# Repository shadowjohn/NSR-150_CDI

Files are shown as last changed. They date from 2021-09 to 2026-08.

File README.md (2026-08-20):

# NSR-150_CDI
利用 Nodemcu V2 開發的 NSR-150 可程式化 CDI
<br>
<br>
<h2>動機：</h2>
騎了NSR五年多，這陣子翻維修手冊，看到 CDI 的接線圖<br>
一直以來都覺得這是一塊很巨大的拚圖，想著想著就推著自己往前走，心中閃過一個想法<br>
不如~來自製一顆可程式的 CDI 吧~~~<br>
<br>
<br>
<h2>
Author：羽山 (https://3wa.tw)<br>
Author：@FB 田峻墉
</h2>
<h2>版本：</h2>
V0.5
<br>
<h2>最初發布時間：</h2>
2021-09-09
<br>
<h2>最後更新時間：</h2>
2026-08-21
<br>
<h2>Nodemcu 使用接腳(V0.1~V0.3版)：</h2>
<ul>
  <li>D1：脈衝 PWM 輸入</li>
  <li>D6：點火 輸出</li>
</ul>
<br>
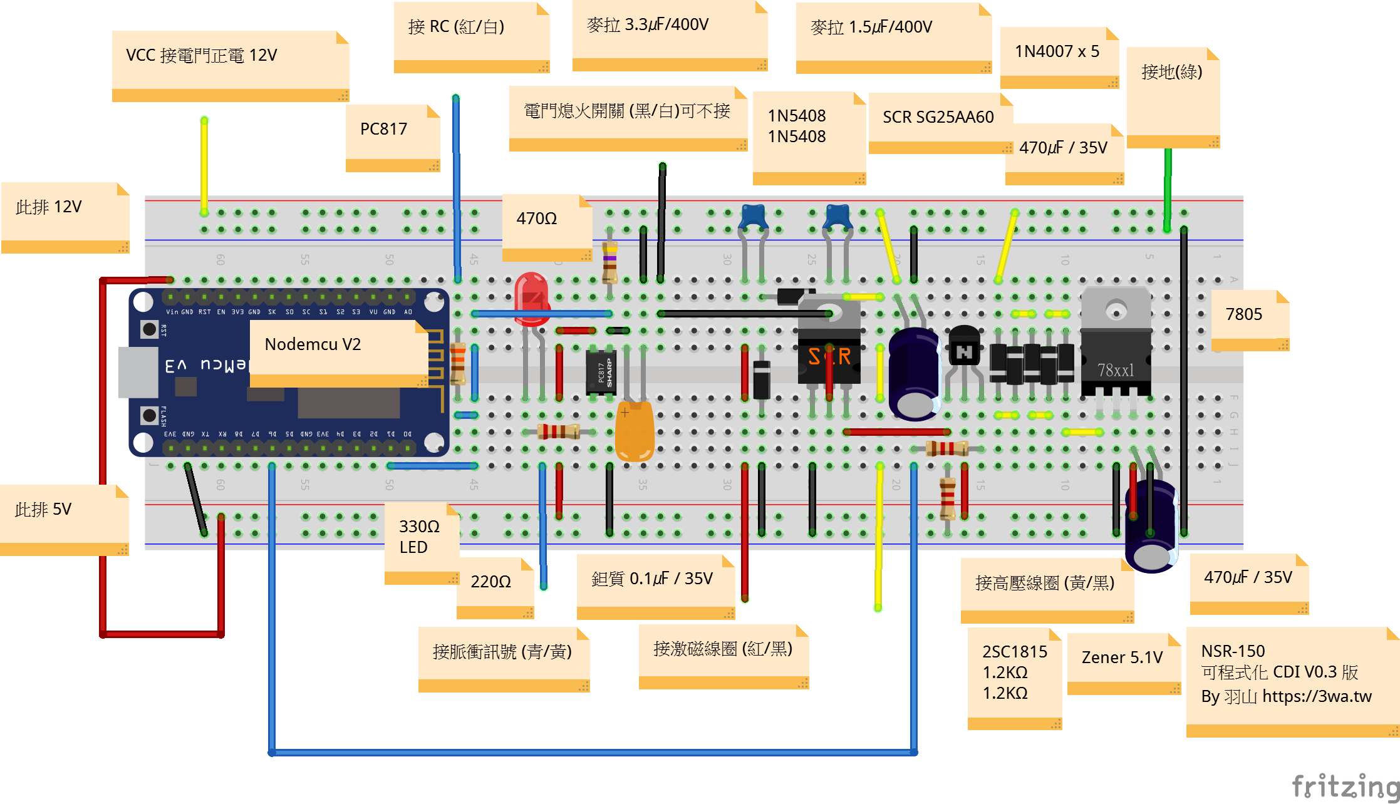
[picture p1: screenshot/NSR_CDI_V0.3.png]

<p align="center">(V0.3 版接線圖)</p>
<br>
<br>
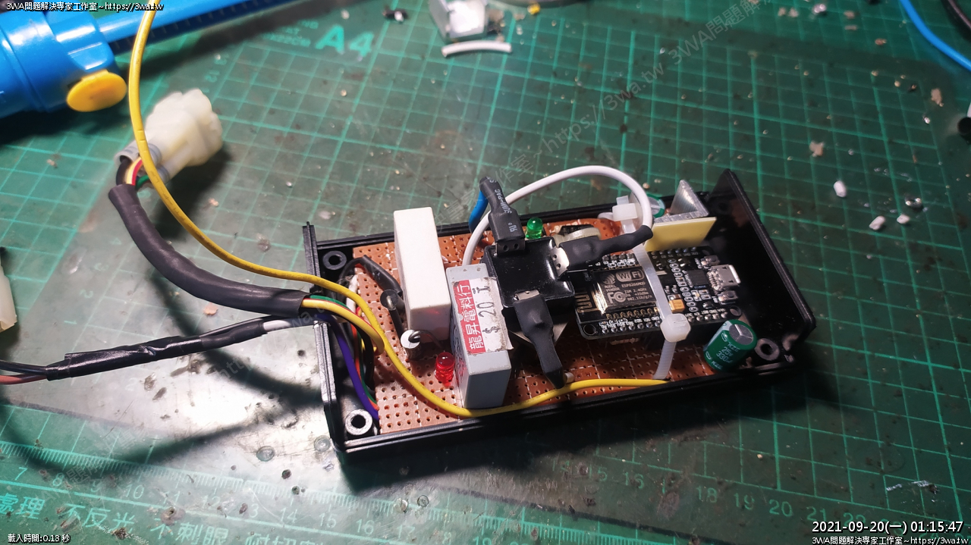
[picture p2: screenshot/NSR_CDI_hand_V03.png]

<p align="center">(V0.3 版成品圖)</p>
<br>
<br>
<h2>Nodemcu 使用接腳(V0.4~V0.5版)：</h2>
<ul>
  <li>D1：脈衝 PWM 輸入</li>
  <li>D4：RC 訊號輸出</li>  
  <li>D6：點火 輸出</li>  
</ul>
<br>
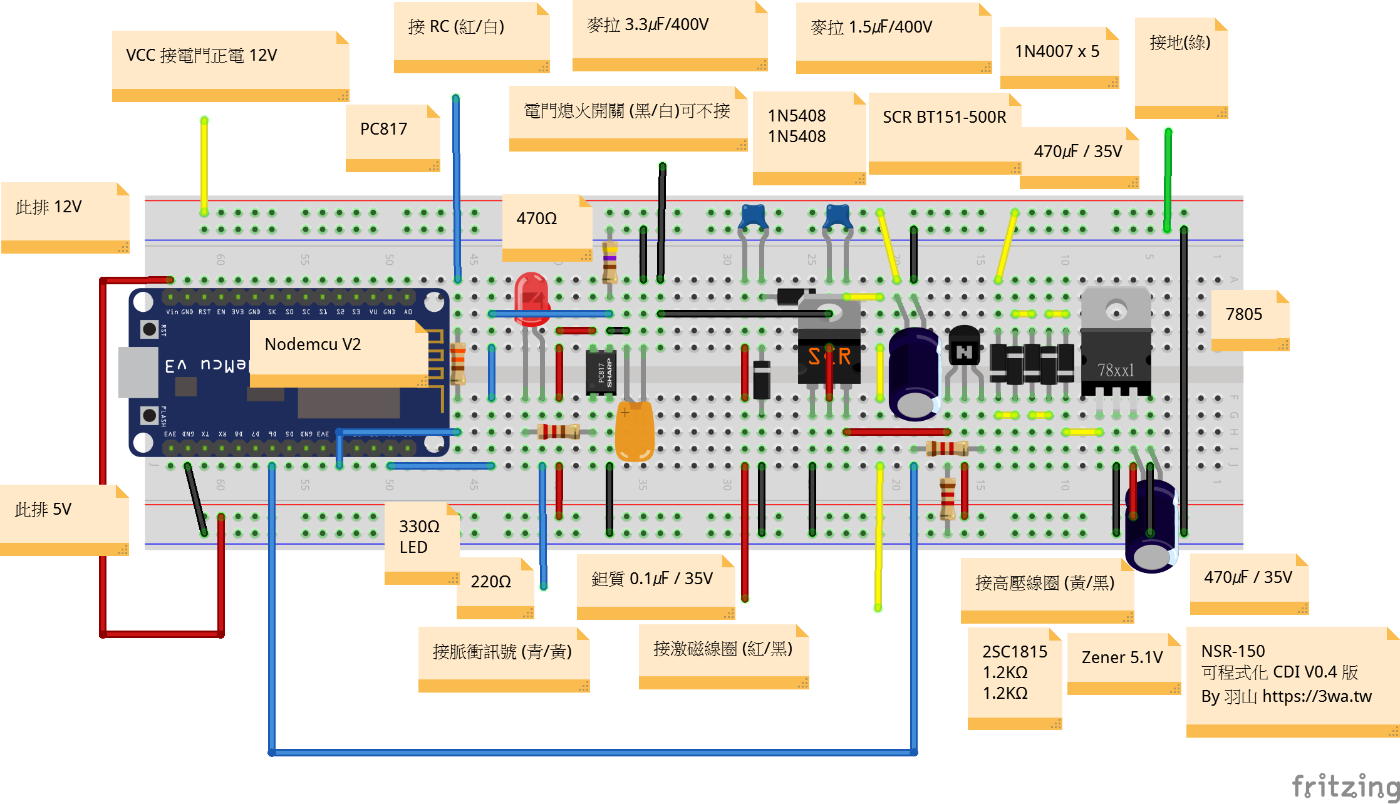
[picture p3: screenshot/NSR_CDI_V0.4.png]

<p align="center">(V0.4 版接線圖)</p>
<br>
<br>
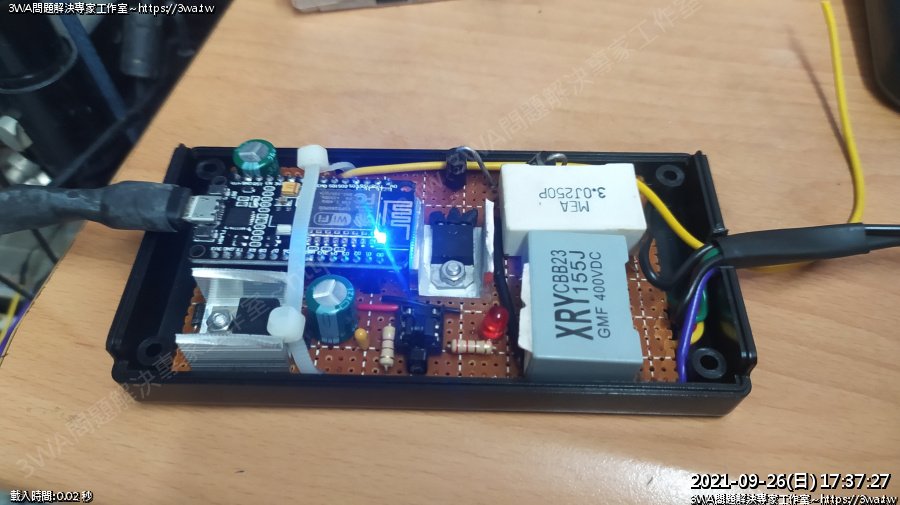
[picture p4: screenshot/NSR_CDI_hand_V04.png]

<p align="center">(V0.4 版成品圖)</p>
<br>
<br>
<br>
<h2>各版本說明：</h2>
<table>
  <thead>
  <tr>
    <th>版本</th>
    <th>補充說明</td>
    <th>適用程式</td>
  </tr>
  </thead>
  <tbody>
  <tr>
    <td>0.1~0.3</td>
    <td>基本版</td>
    <td>      
      (各版本的程式皆可運作)<br>
      https://github.com/shadowjohn/NSR-150_CDI/blob/main/CODE/NSR-150_CDI/NSR-150_CDI.ino <br>
      https://github.com/shadowjohn/NSR-150_CDI/blob/main/CODE/NSR-150_CDI_V0.4/NSR-150_CDI_V0.4.ino
    </td>
  </tr>
  <tr>
    <td>0.4</td>
    <td>
      1.使用 SCR BT151-500R<br>
      2.讓二期的 RC電腦，變成一期 RC電腦的騎乘體驗
    </td>
    <td>            
      需搭配 V0.4 版程式<br>
      https://github.com/shadowjohn/NSR-150_CDI/blob/main/CODE/NSR-150_CDI_V0.4/NSR-150_CDI_V0.4.ino
    </td>
  </tr>
  <tr>
    <td>0.5</td>
    <td>
      1.保留 V0.4 點火角表、RC 5,000 rpm 門檻與 200 us SCR 觸發脈寬<br>
      2.15,000~17,000 rpm 固定使用最後一格 8°，避免點火表插值除以零<br>
      3.使用 ESP8266 Timer1 one-shot 排程點火，避免主迴圈延遲影響點火時序<br>
      4.已通過主機端計時測試與 NodeMCU V2 編譯；尚未完成示波器或實車驗證
    </td>
    <td>
      需搭配 V0.5 版程式<br>
      https://github.com/shadowjohn/NSR-150_CDI/blob/main/CODE/NSR-150_CDI_V0.5/NSR-150_CDI_V0.5.ino
    </td>
  </tr>
  </tbody>
</table>
<br>
<br>
<h2>程式版本說明：</h2>
V0.1：符合 V0.1~V0.3 版電路圖設計<br>
V0.4：RC訊號從 D4 輸出，讓二期 RC 電腦變成一期 RC 電腦的騎乘感覺<br>
V0.5：保留 V0.4 的點火能量相關設定，改用 Timer1 one-shot 排程點火，並修正 15,000 rpm 以上點火表插值邊界<br>
<br>
<h2>V0.5 主機端計時測試：</h2>
在 Windows PowerShell 執行以下命令，可驗證 V0.5 的 RPM 邊界、點火表與延遲計算：<br>
<code>pwsh.exe -ExecutionPolicy Bypass -File .\tests\run_v0.5_timing_test.ps1</code><br>
此測試不會驗證 PC817、SCR、高壓線圈或實際點火角；上車前仍需先以訊號產生器與示波器驗證。
    
<br>
<br>
<h2>免責聲明：</h2>
不要學，你們的車一定會壞掉，哈哈<br>
文章、電路圖與程式皆採滾動式修正
<br>
<br>
<h2>詳細心得參考：</h2>
<ul>
  <li>1. 影片參考：https://youtu.be/g--ht7JCfWI</li>
  <li>2. NSR150 自製可程式 CDI - Part1 (序) https://3wa.tw/blog/blog.php?id=1924</li>
  <li>3. NSR150 自製可程式 CDI - Part2 (研究方法目錄) https://3wa.tw/blog/blog.php?id=1926</li>
  <li>4. NSR150 自製可程式 CDI - Part3 (實作練習V0.1~V0.3版) https://3wa.tw/blog/blog.php?id=1930</li>
  <li>5. NSR150 自製可程式 CDI - Part4 (實作練習V0.4版) https://3wa.tw/blog/blog.php?id=1931</li>
  <li>6. NSR150 自製可程式 CDI 程式說明 (V0.4版)：https://3wa.tw/blog/blog.php?id=1934</li>
</ul>

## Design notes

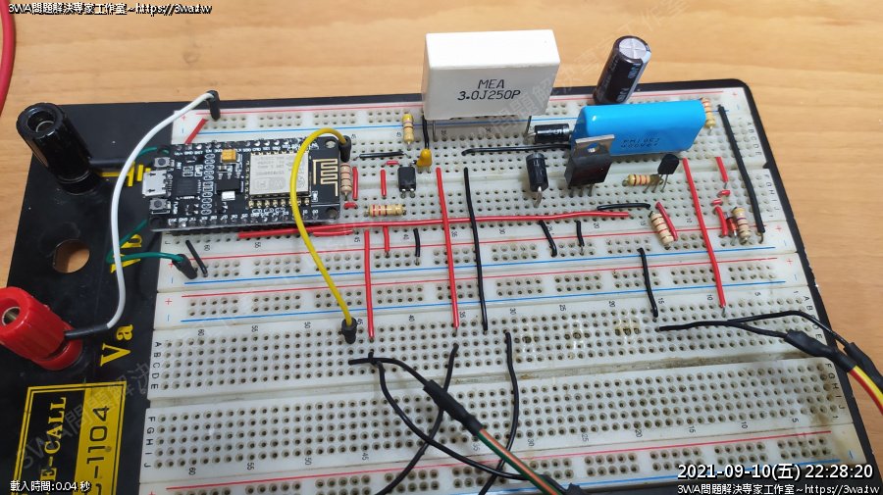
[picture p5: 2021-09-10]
screenshot/NSR_CDI_hand_V01.png

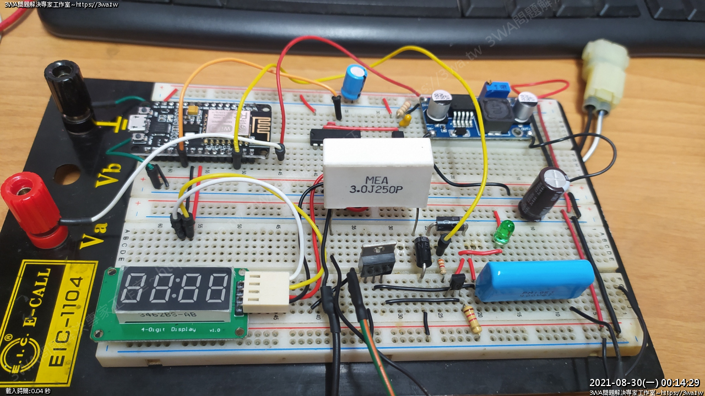
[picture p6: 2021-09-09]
screenshot/NSR_CDI_hand.png

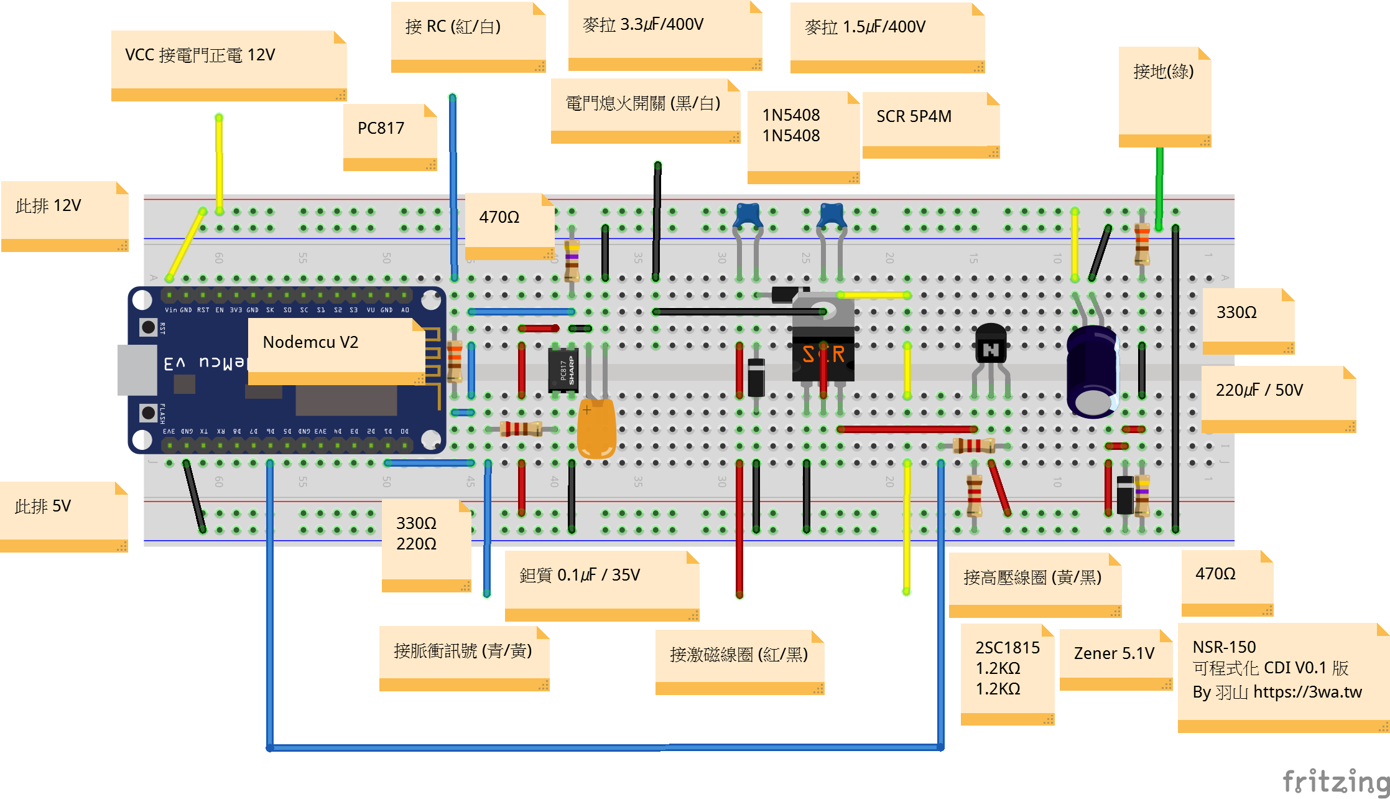
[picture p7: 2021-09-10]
screenshot/NSR_CDI.png

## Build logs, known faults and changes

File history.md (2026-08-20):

# NSR-150_CDI 歷程與研究筆記

## 2026-08-21：V0.4 靜態盤點

### 盤點範圍

- 分支：`main`，工作樹乾淨。
- 讀取 `README.md`、兩份 `.ino` 韌體、Fritzing V0.4 接線圖與既有實作紀錄。
- 初始盤點只做原始碼與電路圖的靜態分析；後續 V0.5 已完成主機端測試與 ESP8266 編譯，但仍未連接實車、量測波形或燒錄。

### 架構確認

- 控制器為 NodeMCU V2（ESP8266）。
- V0.4 接腳：D1 讀取凸台脈衝、D4 輸出 RC 訊號、D6 經 2SC1815 觸發 SCR 點火。
- 脈衝輸入以 PC817 隔離；高壓儲能／點火端使用 BT151-500R、1N5408 與兩顆高耐壓麥拉電容；控制端以二極體降壓後的 7805 供電。
- V0.4 在開機時先輸出 250 次、每次 HIGH/LOW 各 3 ms 的 RC 訊號，再依轉速決定是否繼續輸出 RC 訊號。

### 已確認的程式問題

#### P0：15,000 rpm 以上的點火表插值會除以零

`countup()` 先將 `index` 與 `index_n` 限制在 `0..15`，但在 15,000 rpm 以上兩者都會變成 `15`：

```text
index = 15
index_n = 15
s = 15000
e = 15000
map(rpm, s, e, ss, ee)
```

因此 `map()` 的來源區間為 `15000..15000`，除數為零。程式雖然容許至 17,000 rpm，實際可正常插值的上限只有 14,999 rpm。

處理此問題前，不應在車上測試 15,000 rpm 以上。

### 時序與可維護性觀察

- ISR 取得凸台時戳並算出 `CDI_DELAY`，真正的 `delayMicroseconds()` 卻在 `loop()` 才執行；從 ISR 回到主迴圈的延遲會直接變成額外點火延遲。
- 正式點火流程旁仍保留高頻 `Serial.print()` 偵錯輸出。這會增加主迴圈延遲與點火抖動，應在實車版關閉或改為非同步診斷。
- `isFiring` 是單一旗標而非事件佇列，且 `rpm`、`RPM_DELAY`、`CDI_DELAY` 都由 ISR 與主迴圈共用；後續若重構，應以同一次 ISR 的不可分割快照來排程點火。
- `RPM_DELAY > 598802` 已把低於約 100 rpm 視為停止，後續的 `rpm < 80` 判斷在現有流程中沒有實質作用；最低有效轉速規格應統一。
- V0.4 實作文章說 RC 於 5,500 rpm 以上開啟，現行韌體則使用 `rpm >= 5000`。應確認 5,000 或 5,500 rpm 才是正式設定。

### 建議驗證順序

1. 修正 15,000 rpm 以上的查表邏輯：明確採用最後一格飽和值，或將限轉值降到表格可涵蓋的範圍。
2. 移除正式點火路徑中的 Serial 偵錯，並使排程以 ISR 取得的原始時戳為基準。
3. 先用 555 或訊號產生器與示波器，在低壓邏輯側量測 D1、D6、D4；至少測 1k、5k、10k、14,999 與 15k rpm。
4. 只有在波形、延遲與限轉行為都符合預期後，才接回高壓點火端與實車測試。

### 參考位置

- `README.md`
- `CODE/NSR-150_CDI_V0.4/NSR-150_CDI_V0.4.ino`
- `fritzing/NSR_CDI_V0.4.fzz`
- `https://3wa.tw/blog/blog.php?id=1931`
- `https://3wa.tw/blog/blog.php?id=1934`

## 2026-08-21：V0.5 保守時序調整

### 調整範圍

- 新增 `CODE/NSR-150_CDI_V0.5/NSR-150_CDI_V0.5.ino`，不修改 V0.1~V0.4。
- 保留 V0.4 的點火角表、RC 開啟門檻（5,000 rpm）、200 us SCR 觸發脈寬與高壓回路。
- 不因高壓線圈曾燒毀而猜測性調整電容、SCR、點火角或觸發脈寬。

### 已完成調整

- 點火表改為整數千分之一度計算；0~14,999 rpm 維持線性插值，15,000~17,000 rpm 固定使用最後一格 8°，不會再呼叫零長度的 `map()` 區間。
- 有效轉速統一為 100~17,000 rpm，超出範圍或過慢脈衝都回到不點火狀態。
- 點火表的升角與降角區間都使用有號插值，保留 V0.4 在 4k~5k、5k~6k 等下降區間的既有角度曲線。
- `micros()` 量化後的 3,529 us 脈衝視為 17,000 rpm 上限，避免實際 17,000 rpm 因整數除法算成 17,002 rpm 而漏點火；3,528 us 以下仍拒絕。
- 移除正式點火流程的 Serial 與主迴圈 `delayMicroseconds()`；D1 ISR 以凸台原始時戳扣除運算耗時後，使用 ESP8266 Timer1 one-shot 安排點火。
- Timer1 第一個事件拉高 D6，第二個事件於 200 us 後拉低 D6；每個凸台脈衝只保留一個待執行點火事件，未結束的舊事件會先被安全關閉。
- RC 訊號仍在 5,000 rpm 以上輸出，並在這次點火結束時關閉。

### 驗證結果

- 新增 `tests/v0.5_timing_test.cpp`，已先確認缺少 V0.5 計時模組時編譯失敗，再完成實作後通過。
- 主機端測試通過：100/17,000 rpm 邊界、3,528/3,529/3,530 us 脈衝量化、2,500 rpm 升角插值、4,500 rpm 降角插值、14,999/15,000/17,000 rpm 的最後一格飽和值、4,999/5,000 rpm RC 門檻與 200 us 脈寬常數。
- NodeMCU V2、ESP8266 Arduino Core 3.1.2 編譯通過：V0.5 RAM 28,332 / 80,192 bytes（35%）、IRAM 60,255 / 65,536 bytes（91%）、Flash 232,180 / 1,048,576 bytes（22%）。
- 同環境 V0.4 編譯結果為 IRAM 61,211 / 65,536 bytes（93%）；V0.5 沒有增加 IRAM 壓力。

### 未驗證範圍與上車前檢查

- 尚未量測 D1→D6 延遲抖動、D6 實際脈寬、D4 RC 波形，亦未燒錄或實車測試。
- 上車前先用 555 或訊號產生器，在低壓邏輯側以示波器測試 1k、5k、10k、14,999、15k、17k rpm。
- 確認無重複點火、無重開機、D6 為 200 us、D4 在 5k rpm 門檻正確切換後，才進行原地正時燈與短距離低負載測試。

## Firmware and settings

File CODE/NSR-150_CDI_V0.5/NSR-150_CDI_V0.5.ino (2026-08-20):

/*
 * NSR-150 可程式 CDI
 * Version: V0.5
 *
 * V0.5 保留 V0.4 的點火角表、RC 門檻與 200 us SCR 觸發脈寬，
 * 改由 ESP8266 Timer1 one-shot 排程點火，避免主迴圈延遲改變點火時間。
 *
 * 接腳如下：
 *   D1 凸台脈衝輸入
 *   D4 RC 訊號輸出
 *   D6 點火輸出
 *
 * Release Date: 2026-08-21
 * Author: 羽山秋人 (https://3wa.tw)
 * Author: @FB 田峻墉
 */

#include <Arduino.h>

#include "cdi_timing.h"

const uint8_t ToPin = D1;
const uint8_t RCPin = D4;
const uint8_t FirePin = D6;

// ESP8266 Timer1 在 TIM_DIV16 下為 5 MHz，每一微秒為 5 個 timer ticks。
const uint32_t TimerTicksPerUs = 5UL;
const uint32_t FirePinMask = 1UL << FirePin;
const uint32_t RCPinMask = 1UL << RCPin;

enum TimerPhase : uint8_t {
  TimerIdle = 0,
  TimerWaitingForFire,
  TimerWaitingForRelease
};

volatile TimerPhase timerPhase = TimerIdle;
volatile uint32_t lastPulseAtUs = 0;
volatile uint32_t rpm = 0;
volatile uint32_t rpmDelayUs = 0;
volatile bool hasPreviousPulse = false;

void IRAM_ATTR setFireOutput(bool isHigh) {
  if (isHigh) {
    GPOS = FirePinMask;
  } else {
    GPOC = FirePinMask;
  }
}

void IRAM_ATTR setRCOutput(bool isHigh) {
  if (isHigh) {
    GPOS = RCPinMask;
  } else {
    GPOC = RCPinMask;
  }
}

void IRAM_ATTR stopScheduledOutputs() {
  timer1_disable();
  timerPhase = TimerIdle;
  setFireOutput(false);
  setRCOutput(false);
}

void IRAM_ATTR armTimerUs(uint32_t delayUs) {
  uint32_t ticks = delayUs * TimerTicksPerUs;

  if (ticks == 0) {
    ticks = 1;
  }

  // 單次 Timer1 只服務這次的點火事件，沒有周期性 PWM 或主迴圈等待。
  timer1_enable(TIM_DIV16, TIM_EDGE, TIM_SINGLE);
  timer1_write(ticks);
}

void IRAM_ATTR onFireTimer() {
  if (timerPhase == TimerWaitingForFire) {
    setFireOutput(true);
    timerPhase = TimerWaitingForRelease;
    timer1_write(NSR150CDI::kSparkPulseWidthUs * TimerTicksPerUs);
    return;
  }

  if (timerPhase == TimerWaitingForRelease) {
    stopScheduledOutputs();
    return;
  }

  // 非預期的 Timer1 中斷一律回到不點火狀態。
  stopScheduledOutputs();
}

void IRAM_ATTR countup() {
  const uint32_t pulseAtUs = micros();

  if (!hasPreviousPulse) {
    lastPulseAtUs = pulseAtUs;
    hasPreviousPulse = true;
    return;
  }

  const uint32_t elapsedUs = pulseAtUs - lastPulseAtUs;

  if (elapsedUs < NSR150CDI::kMinimumPulseIntervalUs) {
    // 保留最後一個合理脈衝作為基準，忽略過快的雜訊或不可能轉速。
    return;
  }

  lastPulseAtUs = pulseAtUs;
  rpmDelayUs = elapsedUs;

  if (!NSR150CDI::isValidPulseIntervalUs(elapsedUs)) {
    rpm = 0;
    stopScheduledOutputs();
    return;
  }

  const uint32_t currentRpm = NSR150CDI::calculateRpmFromPulseIntervalUs(elapsedUs);

  if (currentRpm == 0) {
    rpm = 0;
    stopScheduledOutputs();
    return;
  }

  rpm = currentRpm;

  // 正常轉速下前一個事件應已結束；若未結束，先停火，不累積或重複點火。
  if (timerPhase != TimerIdle) {
    stopScheduledOutputs();
  }

  const NSR150CDI::Timing timing = NSR150CDI::calculateTiming(currentRpm);
  setRCOutput(timing.rcEnabled);

  // 點火延遲必須從凸台脈衝起算，而不是從 ISR 或主迴圈稍後開始。
  const uint32_t calculationUs = micros() - pulseAtUs;
  const uint32_t remainingDelayUs = timing.fireDelayUs > calculationUs
    ? timing.fireDelayUs - calculationUs
    : 1UL;

  timerPhase = TimerWaitingForFire;
  armTimerUs(remainingDelayUs);
}

void setup() {
  pinMode(ToPin, INPUT_PULLUP);
  pinMode(RCPin, OUTPUT);
  pinMode(FirePin, OUTPUT);
  setRCOutput(false);
  setFireOutput(false);

  // 保留 V0.4 開機後先讓 RC 全開一次、再關閉的行為。
  for (uint16_t i = 0; i < 250; ++i) {
    setRCOutput(true);
    delayMicroseconds(3000);
    setRCOutput(false);
    delayMicroseconds(3000);
  }

  timer1_isr_init();
  timer1_attachInterrupt(onFireTimer);
  timer1_disable();
  attachInterrupt(digitalPinToInterrupt(ToPin), countup, RISING);
}

void loop() {
  // 點火全由外部中斷與 Timer1 處理；主迴圈不執行 Serial 或等待工作。
  yield();
}

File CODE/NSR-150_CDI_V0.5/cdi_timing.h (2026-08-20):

#ifndef NSR150_CDI_TIMING_H
#define NSR150_CDI_TIMING_H

#include <stdint.h>

namespace NSR150CDI {

static const uint32_t kMinimumRpm = 100UL;
static const uint32_t kMaximumRpm = 17000UL;
static const uint32_t kRcEnableRpm = 5000UL;
static const uint32_t kSparkPulseWidthUs = 200UL;
static const uint32_t kFullAdvanceMilliDegrees = 65000UL;
static const uint32_t kAdvanceTableLastRpm = 15000UL;
static const uint32_t kMinimumPulseIntervalUs = 60000000UL / kMaximumRpm;
static const uint32_t kMaximumPulseIntervalUs = 60000000UL / kMinimumRpm;

// 保留 V0.4 實車使用的點火表，單位改為千分之一度以避開 ISR 浮點運算。
static const uint16_t kAdvanceTableMilliDegrees[] = {
  10000, 12000, 12000, 25000,
  26000, 23000, 20000, 16000,
  13000, 9000,  9000,  9000,
  8000,  8000,  8000,  8000
};

struct Timing {
  uint32_t rpm;
  uint32_t advanceMilliDegrees;
  uint32_t fireDelayUs;
  bool rcEnabled;
};

inline bool isValidRpm(uint32_t rpm) {
  return rpm >= kMinimumRpm && rpm <= kMaximumRpm;
}

inline bool isValidPulseIntervalUs(uint32_t pulseIntervalUs) {
  return pulseIntervalUs >= kMinimumPulseIntervalUs &&
    pulseIntervalUs <= kMaximumPulseIntervalUs;
}

inline uint32_t calculateRpmFromPulseIntervalUs(uint32_t pulseIntervalUs) {
  if (!isValidPulseIntervalUs(pulseIntervalUs)) {
    return 0;
  }

  const uint32_t calculatedRpm = 60000000UL / pulseIntervalUs;

  // micros() 的一微秒量化會讓實際 17,000 rpm 落在 3,529 us，
  // 因此只在合法脈衝區間內將計算值飽和至既定限轉值。
  return calculatedRpm > kMaximumRpm ? kMaximumRpm : calculatedRpm;
}

inline uint32_t calculateAdvanceMilliDegrees(uint32_t rpm) {
  if (rpm >= kAdvanceTableLastRpm) {
    return kAdvanceTableMilliDegrees[15];
  }

  const uint32_t index = rpm / 1000UL;
  const uint32_t remainder = rpm % 1000UL;
  const int32_t lower = kAdvanceTableMilliDegrees[index];
  const int32_t upper = kAdvanceTableMilliDegrees[index + 1UL];

  return static_cast<uint32_t>(
    lower + ((static_cast<int32_t>(remainder) * (upper - lower)) / 1000L)
  );
}

inline Timing calculateTiming(uint32_t rpm) {
  Timing timing;
  timing.rpm = rpm;
  timing.advanceMilliDegrees = calculateAdvanceMilliDegrees(rpm);
  timing.fireDelayUs = static_cast<uint32_t>(
    (60000000ULL * (kFullAdvanceMilliDegrees - timing.advanceMilliDegrees)) /
    (static_cast<uint64_t>(rpm) * 360000ULL)
  );
  timing.rcEnabled = rpm >= kRcEnableRpm;
  return timing;
}

}  // namespace NSR150CDI

#endif

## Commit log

2021-09-09 更新動機
2021-09-09 加入日期
2021-09-09 腳位跟名稱修改
    [NSR_CDI.fzz]
2021-09-09 更新RC腳位接法
    [NSR_CDI.fzz]
2021-09-09 更新接線圖
    [NSR_CDI.fzz]
2021-09-10 更新RC電路圖
    [NSR_CDI.fzz]
2021-09-10 更新電路圖
    [NSR_CDI.fzz]
2021-09-10 更新手接線圖
2021-09-10 更新電路圖、說明
    [NSR_CDI.fzz]
2021-09-11 更新程式碼資訊、ADV角度
2021-09-15 補1N4007
    [NSR_CDI.fzz]
2021-09-19 調整點火時間為羽山量到的值
2021-09-20 更新電路圖V0.3
    [NSR_CDI.fzz]
2021-09-26 簽入0.4版
2021-09-26 0.04 改0.4
2021-09-26 加入 V0.4 電路圖 修正 V0.2、V0.3 電路圖
    [NSR_CDI.fzz, NSR_CDI_V0.4.fzz]
2021-09-26 更新電路圖info
    [NSR_CDI_V0.4.fzz]
2021-09-30 Add files via upload
    加入V0.4手接圖
2021-09-30 Update README.md
    更新說明
2026-08-20 Add V0.5 Timer1 timing control
